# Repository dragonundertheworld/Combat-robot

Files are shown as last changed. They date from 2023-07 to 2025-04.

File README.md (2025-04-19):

# Eternity Fighting Robot Design
Project details can be found in [notion link](https://cherry-room-163.notion.site/0f15df8a2a594116ac27361bd8c10d9d?pvs=4)
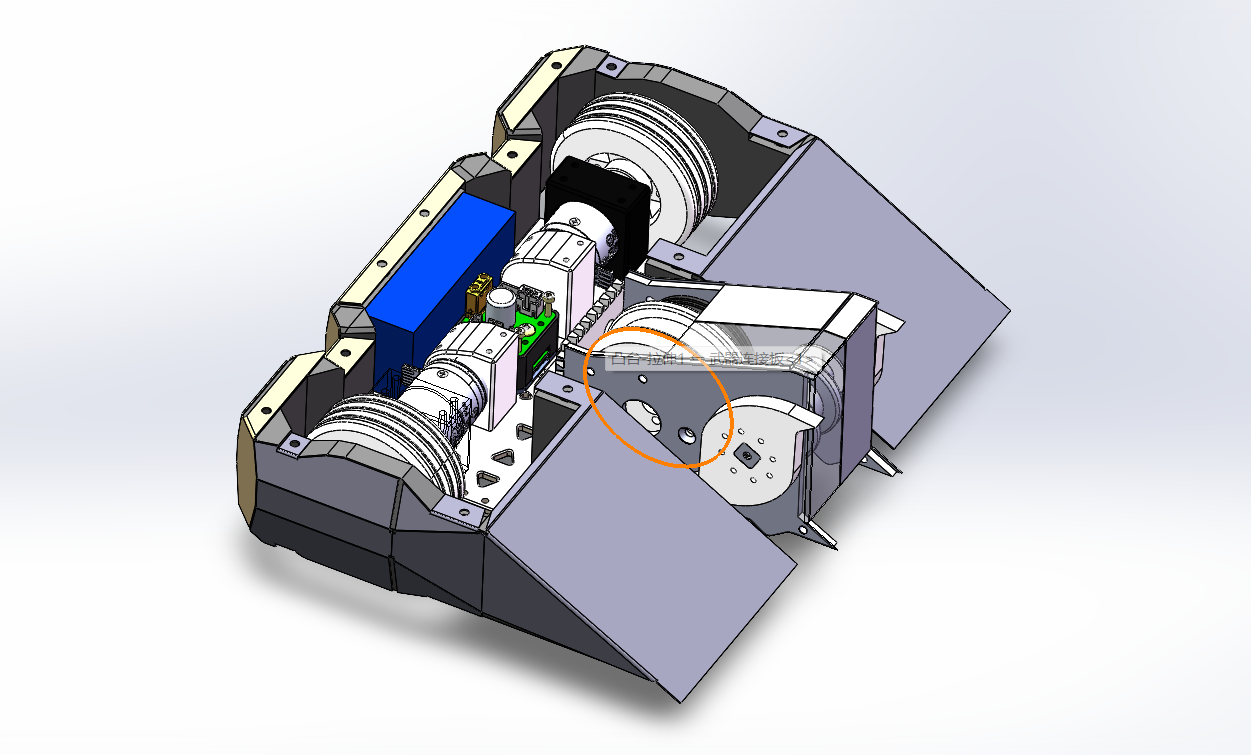
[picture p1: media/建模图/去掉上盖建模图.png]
CAD

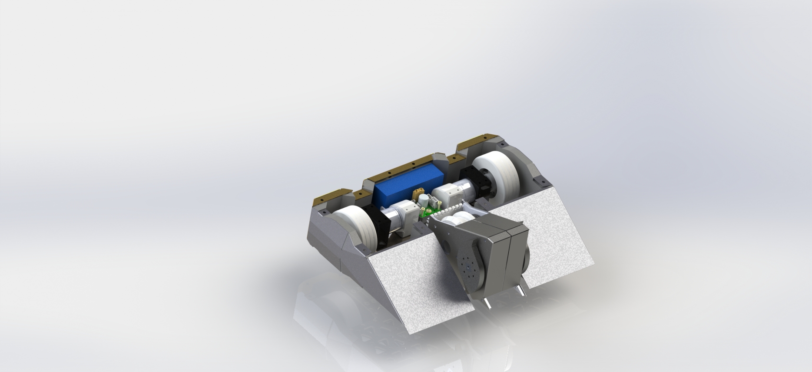
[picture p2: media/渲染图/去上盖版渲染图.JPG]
Rendering

A comprehensive design for a 1v1 “Eternity” fighting robot developed by the University of Electronic Science and Technology of China. This project covers mechanical architecture, drive and attack systems, electronics & control, innovative features, and iterative testing & optimization.

---

## Table of Contents

- [Eternity Fighting Robot Design](#eternity-fighting-robot-design)
  - [Table of Contents](#table-of-contents)
  - [Project Overview](#project-overview)
  - [Mechanical Design](#mechanical-design)
    - [Drive System](#drive-system)
    - [Attack Mechanism](#attack-mechanism)
  - [Electronics \& Control](#electronics--control)
    - [Communication \& Remote Control](#communication--remote-control)
    - [Motor \& Power Components](#motor--power-components)
    - [Main Controller \& Safety](#main-controller--safety)
  - [Innovations \& Materials](#innovations--materials)
    - [Structural Innovations](#structural-innovations)
    - [Material \& Armor](#material--armor)
    - [Modular Architecture](#modular-architecture)
  - [Testing \& Optimization](#testing--optimization)
  - [Team \& Roles](#team--roles)
  - [Build \& Assembly Instructions](#build--assembly-instructions)
  - [License \& Acknowledgements](#license--acknowledgements)

---

## Project Overview

“Eternity” is a compact, four-wheel platform with deployable legs (“4‑wheel 4‑joint” configuration).  
- **Modes**:  
  - **Wheeled mode** for high-speed traversal  
  - **Quasi‑static climbing mode** for stair and obstacle engagement  
- **Climbing cycle**: Approach → Lift → Traction → Reset  
- Maintains stability by keeping at least three “legs” (wheels) in contact with the ground.

---

## Mechanical Design

### Drive System

- **Configuration**: Two‑wheel differential drive  
- **Key Attributes**:
  - Stability
  - Speed control
  - Maneuverability
  - Reliability

### Attack Mechanism

- **Primary Weapon**: Vertical spinner (“tip‑over” rotor)  
- **Supplementary**: Wedge‑style pusher  
- **Advantages**:
  - High-impact vertical blows
  - Low‑profile wedge can lift opponent’s center of gravity  
- **Trade‑offs** vs. horizontal spinners & drum weapons:
  - Reduced “self‑impulse” risk
  - Simpler fabrication and lower cost  
- **Operator Training**: Minimizes precision demands and maximizes damage output.

---

## Electronics & Control

### Communication & Remote Control

- **Technology**: LoRa (Semtech SX1276/78)  
- **Module**: ATK‑LORA  
- **Benefits**:
  1. Long‐range (several kilometers)
  2. Low power consumption
  3. Compact form factor  
- **Interface**: UART

### Motor & Power Components

| Component | Specification |
|---|---|
| **Weapon Motor** | M3508 (no gearbox)  
   - Rated Voltage: 24 V  
   - No‑load Speed: 9,158 rpm  
   - Max Torque: 0.15 Nm |  
| **Weapon ESC**        | C620 Brushless Controller  
   - Weight: 35 g  
   - Voltage: 24 V  
   - Signal: CAN & PWM  
   - Dimensions: 49.4×25.8×11.5 mm |  
| **Drive Motors**      | 2 × Hub motors |  
| **Battery**           | FPV LiPo 3S (11.1 V, 1,300 mAh, 110 C) |

### Main Controller & Safety

- **MCU**: X‑mind C1  
  - Drives up to 5 motor channels via PWM  
  - On‑board screw switch & 3S battery input  
- **CAN Bridge**: F103C8T6  
  - Converts PWM → CAN for ESCs  
- **Safety Systems**:
  1. **Unlock Card**: Limits weapon output to ≤10% if missing  
  2. **Signal Loss Protection**: C8T6 cuts motor commands on remote disconnect  

---

## Innovations & Materials

### Structural Innovations

- **Mortise & Tenon**: “Exposed dovetail” connection for weapon module  
- **Invert Walk**: Weapon top edge co‑planar with wheels when flipped, enabling upside‑down driving

### Material & Armor

- **Weapon Blades**:
  - Manganese steel, 6 mm thick, comma‑shaped tip  
- **Armor**:
  - TPU shell for energy absorption  
- **Tires**:
  - 55 mm high‑friction “camelback” profile

### Modular Architecture

- **Interchangeable Modules**:
  - Rapid swapping of drive, weapon, or armor packs  
  - Simplified maintenance & upgrade paths

---

## Testing & Optimization
[weighting](./media/测试视频/第三版测重.mp4), [drive power testing](./media/测试视频/第三版推力测试.mp4) and [weapon testing](./media/测试视频/第三版武器测试.mp4)
1. **Version 1** – Proof‑of‑concept CAD & basic drive tests  
2. **Version 2** – Refined frame geometry, improved stability  
3. **Version 3** – Acrylic & 3D‑printed prototypes for live arena trials  
4. **Identified Issues**:
   - Excessive overall height  
   - Simplistic armor  
   - Lack of flip resistance  
   - Crowded internal layout  
5. **Optimizations**:
   - Lowered chassis center of gravity  
   - Redesigned armor geometry & thickness  
   - Integrated anti‑flip skids  
   - Re‑routed electronics into wedge cavity for space efficiency

---

## Team & Roles

| Member | Role |
|---|---|
| 曹知寒 | Lead mechanical design; assembly |
| 刘天羽 | Electronics design & control tuning |
| 王启宇 | Mechanical assembly; secondary design; driver |
| 王浩宇 | Team operations & coordination |
| **Advisors** | 何瑜, 彭倍 |

---

## Build & Assembly Instructions

1. **Prerequisites**:  
   - CAD software for 3D model viewing (e.g., SolidWorks, Fusion360)  
   - 3D printer or CNC for prototypes  
2. **Mechanical Assembly**:  
   - Fabricate chassis plates, dovetail fixtures  
   - Install drive & weapon motors with gear mounts  
   - Attach TPU armor panels  
3. **Electrical Wiring**:  
   - Wire X‑mind C1 → F103C8T6 → ESCs (CAN bus)  
   - Route battery & LoRa antenna  
4. **Software Setup**:  
   - Flash microcontroller firmware (STM32CubeIDE)  
   - Configure LoRa remote pairing  
5. **Trial Runs**:  
   - Verify drive control & weapon spin under no‑load  
   - Test safety interlocks (unlock card, signal loss)  
   - Full‑power arena tests with soft obstacles

---

## License & Acknowledgements

- This design is the property of the UESTC.  
- **Disclaimer**: Do not reproduce, distribute, or sell without permission.

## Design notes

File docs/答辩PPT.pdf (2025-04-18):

感谢您下载包图网平台上提供的PPT作品，为了您和包图网以及原创作者的利益，请勿复制、传播、销售，否则将承担法律责任！包图网将对作品进行维权，按照传播下载次数进行十倍的索取赔偿！

# ibaotu.com 电子科技大学

# Eternity

# 格斗机器人设计报告

# 团队成员

# 曹知寒、刘天羽、王启宇、王浩宇

# 指导老师

# 何瑜、彭倍

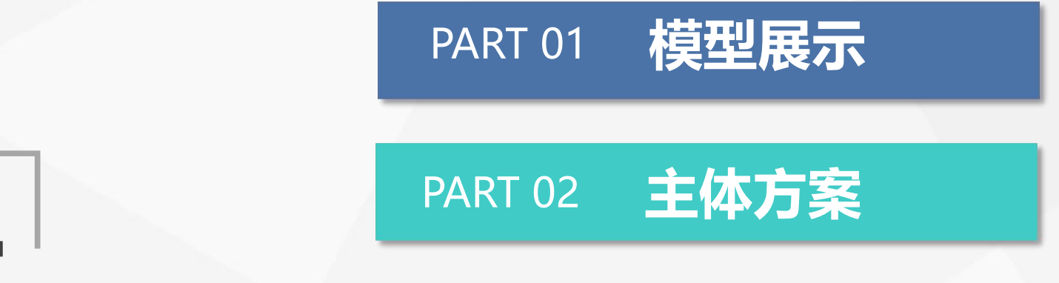
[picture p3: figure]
ibaotu.com; PART 01 模型展示; PART 02; 主体方案

感谢您下载包图网平台上提供的PPT作品，为了您和包图网以及原创作者的利益，请勿复制、传播、销售，否则将承担法律责任！包图网将对作品进行维权，按照传播下载次数进行十倍的索取赔偿！

目录

# CONTENTS

感谢您下载包图网平台上提供的PPT作品，为了您和包图网以及原创作者的利益，请勿复制、传播、销售，否则将承担法律责任！包图网将对作品进行维权，按照传播下载次数进行十倍的索取赔偿！

# ibaotu.com模型展示

01

# ibaotu.com 三维模型渲染图

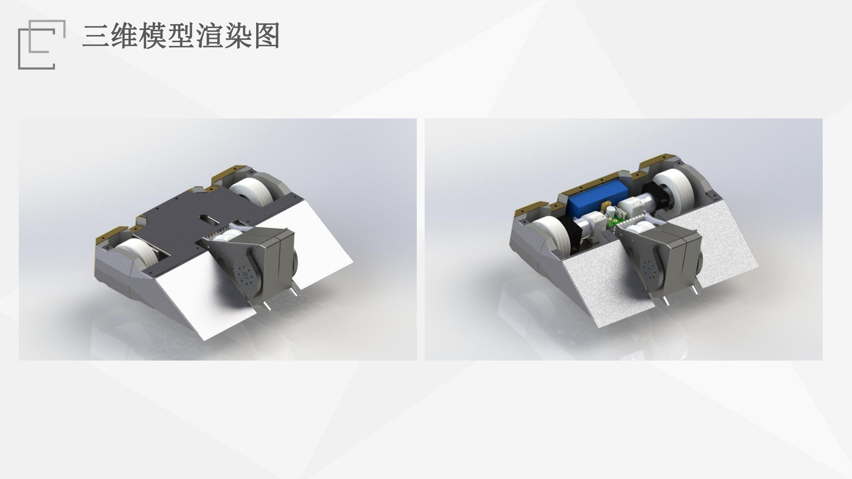
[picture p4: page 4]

感谢您下载包图网平台上提供的PPT作品，为了您和包图网以及原创作者的利益，请勿复制、传播、销售，否则将承担法律责任！包图网将对作品进行维权，按照传播下载次数进行十倍的索取赔偿！

# ibaotu.com 爆炸视图

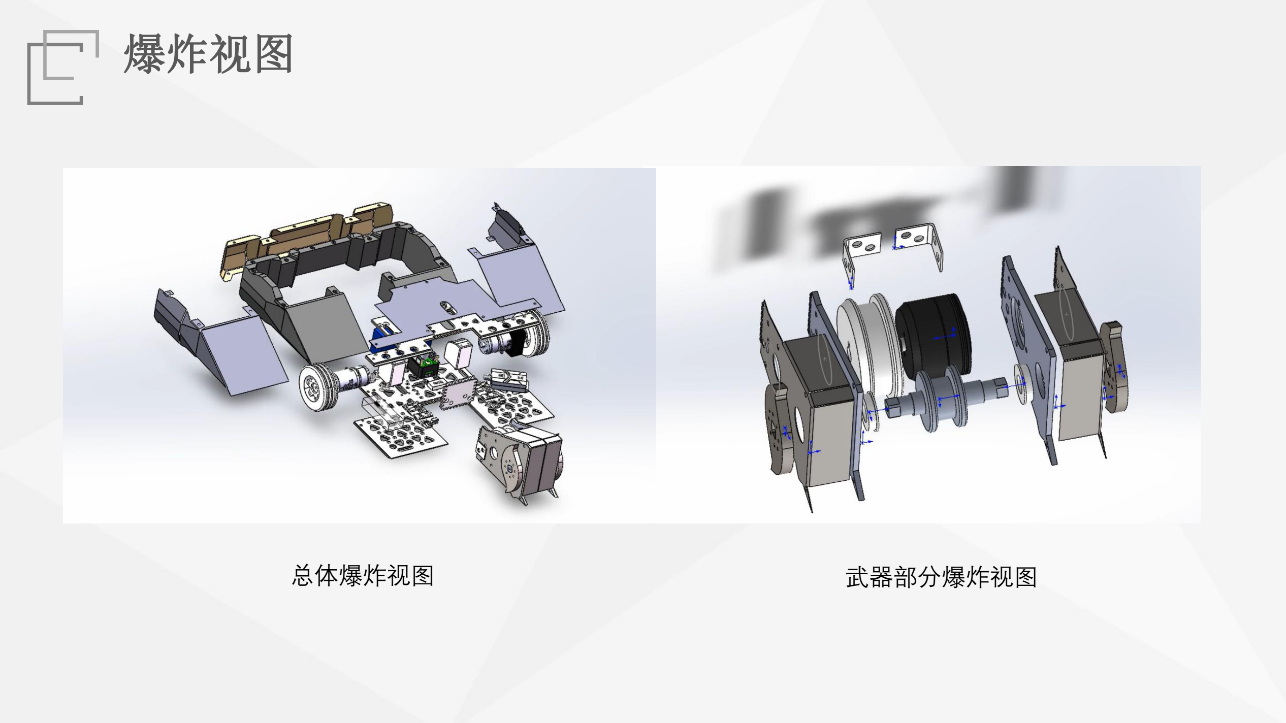
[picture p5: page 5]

感谢您下载包图网平台上提供的PPT作品，为了您和包图网以及原创作者的利益，请勿复制、传播、销售，否则将承担法律责任！包图网将对作品进行维权，按照传播下载次数进行十倍的索取赔偿！

总体爆炸视图 | 武器部分爆炸视图

感谢您下载包图网平台上提供的PPT作品，为了您和包图网以及原创作者的利益，请勿复制、传播、销售，否则将承担法律责任！包图网将对作品进行维权，按照传播下载次数进行十倍的索取赔偿！

# ibaotu.com主体方案

02

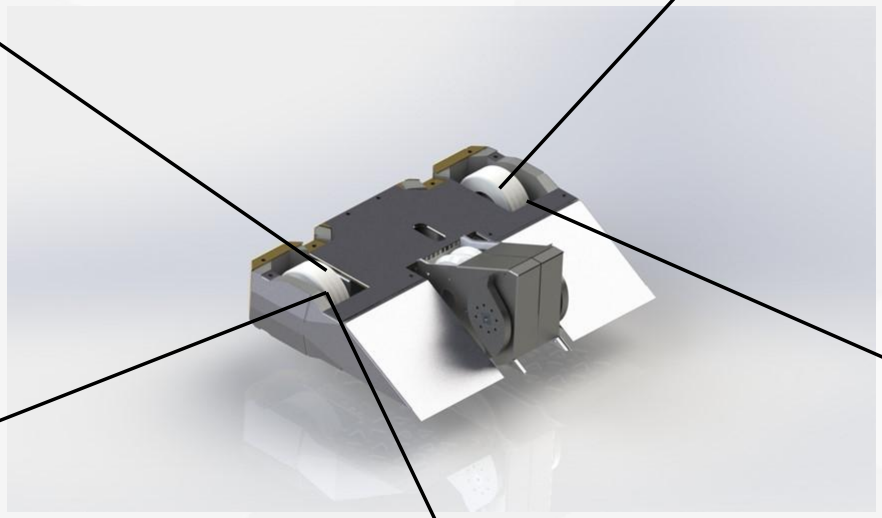
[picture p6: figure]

感谢您下载包图网平台上提供的PPT作品，为了您和包图网以及原创作者的利益，请勿复制、传播、销售，否则将承担法律责任！包图网将对作品进行维权，按照传播下载次数进行十倍的索取赔偿！

# ibaotu.com 移动方式：二轮差速

# 稳定性

控制性 | 快速性

# 灵活性

# 可靠性

感谢您下载包图网平台上提供的PPT作品，为了您和包图网以及原创作者的利益，请勿复制、传播、销售，否则将承担法律责任！包图网将对作品进行维权，按照传播下载次数进行十倍的索取赔偿！

# ibaotu.com 攻击方式：主要使用竖转，辅以楔形攻击

竖转与横转、转鼓和撞击攻击方式的对比 | 缺点
避免被自己的冲击力甩到一边，同时也能 让自己牢牢地抓地 | 对控制者的要求较高

# 增加攻击能量 造成更大的破坏

制造工艺简单且成本低廉 | 相比圆盘或横杆破坏力也较小

# 通过训练控制者，可以最大程度上弥补前两项缺点；同时结合楔形攻击方式的 优点，即可以利用低姿态来铲起对手，可以令对手的重心抬高的同时更好地击 中对方的底部。另外楔形还可以将其他机器人推入竞技场的OUTA区域。

感谢您下载包图网平台上提供的PPT作品，为了您和包图网以及原创作者的利益，请勿复制、传播、销售，否则将承担法律责任！包图网将对作品进行维权，按照传播下载次数进行十倍的索取赔偿！

# ibaotu.com电控方案

03

# ibaotu.com 整体方案

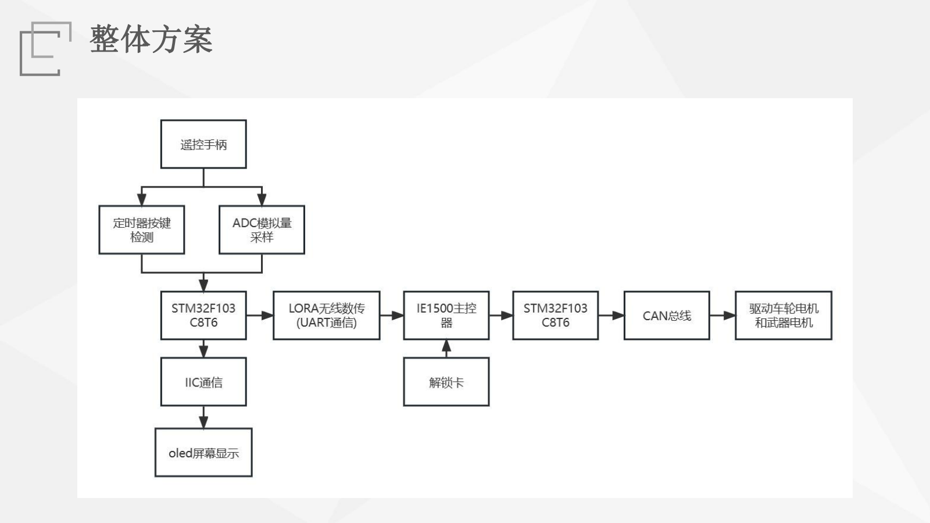
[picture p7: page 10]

感谢您下载包图网平台上提供的PPT作品，为了您和包图网以及原创作者的利益，请勿复制、传播、销售，否则将承担法律责任！包图网将对作品进行维权，按照传播下载次数进行十倍的索取赔偿！

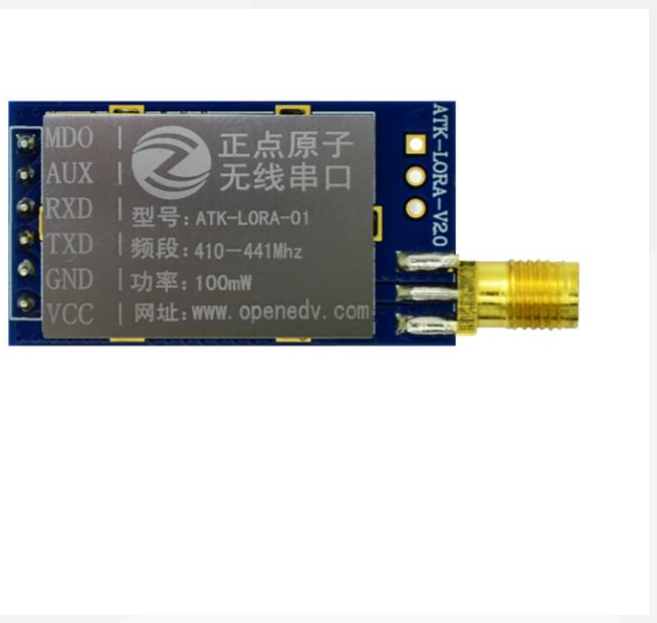
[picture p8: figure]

感谢您下载包图网平台上提供的PPT作品，为了您和包图网以及原创作者的利益，请勿复制、传播、销售，否则将承担法律责任！包图网将对作品进行维权，按照传播下载次数进行十倍的索取赔偿！

# ibaotu.com 遥控系统

# LoRa是一种低功耗远程无线通信技术。它是基于 Semtech公司SX1276/1278芯片开发的无线数传模 块，这种芯片集成规模小、效率高，从而让LoRa 模块拥有高接收灵敏度。

# 1. 作为低功耗广域网的LoRa技术，无线通信距离可以达到几公里，相对WIFI模块而 言，距离要远得多。 2. 相较于无人机常用的遥控接收器，体积更小，且使用UART模式，容易适配多种 遥控器。

# 正点原子ATK-LORA

优势

# ibaotu.com 车轮电机

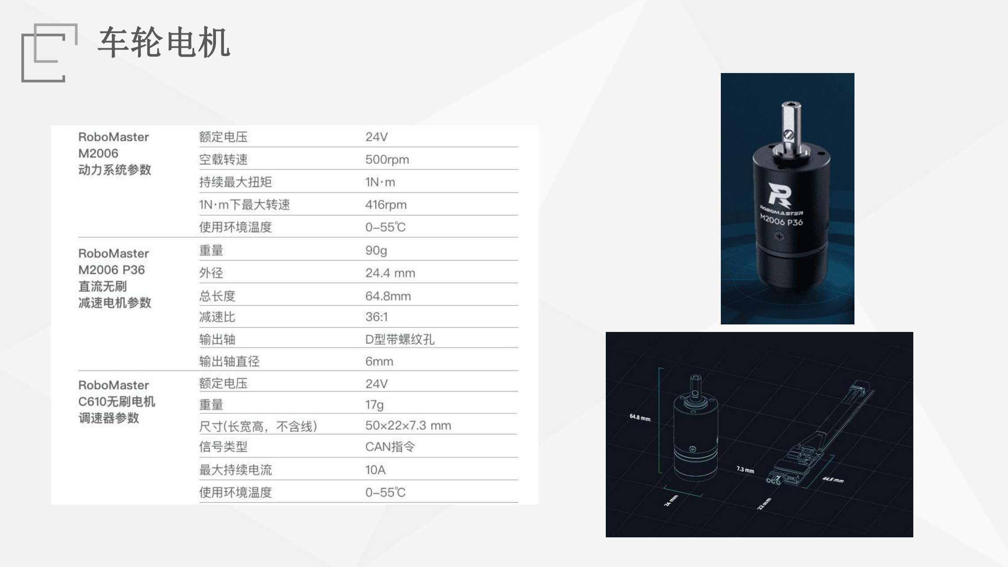
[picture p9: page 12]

感谢您下载包图网平台上提供的PPT作品，为了您和包图网以及原创作者的利益，请勿复制、传播、销售，否则将承担法律责任！包图网将对作品进行维权，按照传播下载次数进行十倍的索取赔偿！

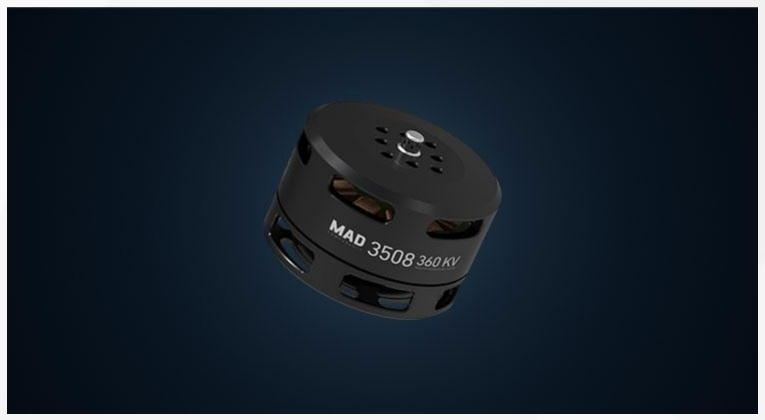
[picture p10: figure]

感谢您下载包图网平台上提供的PPT作品，为了您和包图网以及原创作者的利益，请勿复制、传播、销售，否则将承担法律责任！包图网将对作品进行维权，按照传播下载次数进行十倍的索取赔偿！

# ibaotu.com 武器电机

# 电机型号：M3508(去减速器)

# 额定电压：24V

# 空载转速：9158rpm

# 持续最大扭矩：0.15Nm

# C620无刷电机调速器

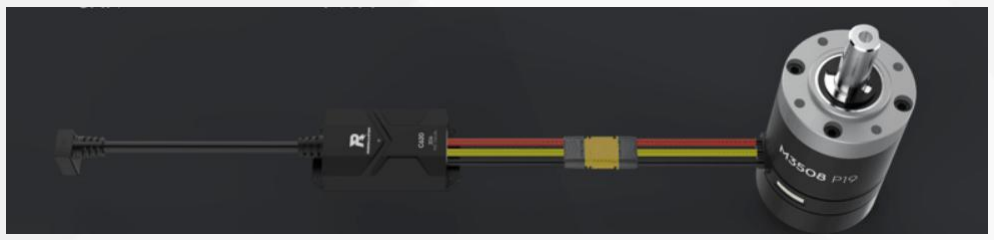
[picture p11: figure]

# 重量:35g 额定电压:24V

# 带线总长度:359mm

# 信号类型:CAN指令、PWM

# 长宽高:49.4*25.8*11.5mm

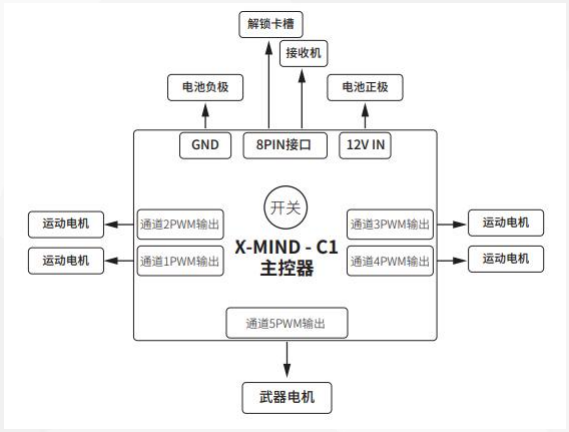
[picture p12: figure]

感谢您下载包图网平台上提供的PPT作品，为了您和包图网以及原创作者的利益，请勿复制、传播、销售，否则将承担法律责任！包图网将对作品进行维权，按照传播下载次数进行十倍的索取赔偿！

# ibaotu.com 主控器

# X-mind C1主控器采用高性能主控芯片，接口 丰富、集成度高，可同 时驱动5套动力系统。

接口：

# 四路运动电机pwm接口

# 一路武器电机pwm接口

# 主控器螺丝开关

# 3S电池供电接口

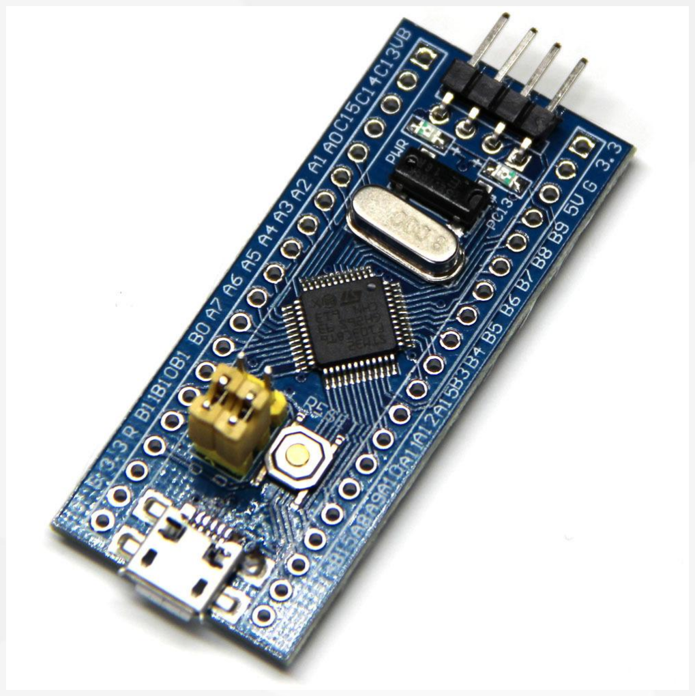
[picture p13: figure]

感谢您下载包图网平台上提供的PPT作品，为了您和包图网以及原创作者的利益，请勿复制、传播、销售，否则将承担法律责任！包图网将对作品进行维权，按照传播下载次数进行十倍的索取赔偿！

# ibaotu.com F103C8T6

# 由于本团队采用的电机控制方式为CAN总线信 号控制，无法直接将主控器的pwm控制信号与 电机直连。

# 因此选用带有CAN信号收发功能的F103C8T6作 为信号转发，在接受主控器pwm信号的同时向 电机发送CAN总线信号。

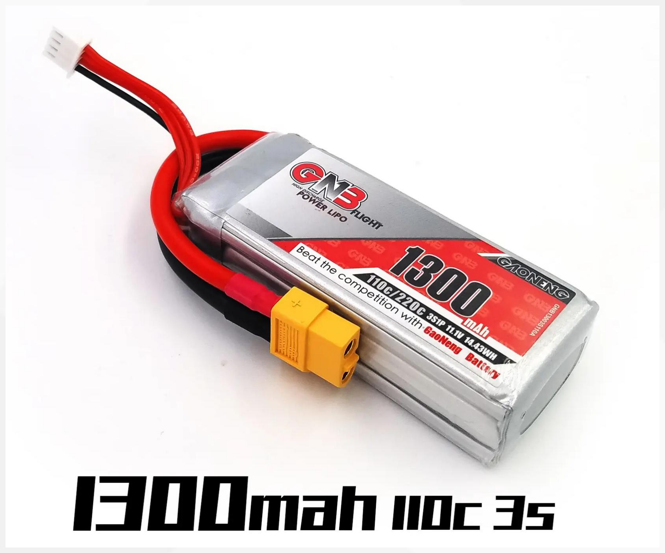
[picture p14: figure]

感谢您下载包图网平台上提供的PPT作品，为了您和包图网以及原创作者的利益，请勿复制、传播、销售，否则将承担法律责任！包图网将对作品进行维权，按照传播下载次数进行十倍的索取赔偿！

# ibaotu.com 电池

# FPV穿越机电池

# 3s/电压11.1V

# 1300mah 110c

感谢您下载包图网平台上提供的PPT作品，为了您和包图网以及原创作者的利益，请勿复制、传播、销售，否则将承担法律责任！包图网将对作品进行维权，按照传播下载次数进行十倍的索取赔偿！

ibaotu.com 电控 | 机器人安全系统

# 解锁卡功能 当X-mind C1主控器未插入解锁卡时，武器电机控制通道的输出功率将低于最 大输出功率的10%。

# 遥控安全功能 当无遥控信号异常时，C8T6会主动停止发送电机端的控制信号，防止小车失控。

感谢您下载包图网平台上提供的PPT作品，为了您和包图网以及原创作者的利益，请勿复制、传播、销售，否则将承担法律责任！包图网将对作品进行维权，按照传播下载次数进行十倍的索取赔偿！

# ibaotu.com自主创新

04

# ibaotu.com 结构创新

# 武器模块与车身的连接采用榫卯结构中的明燕尾榫，

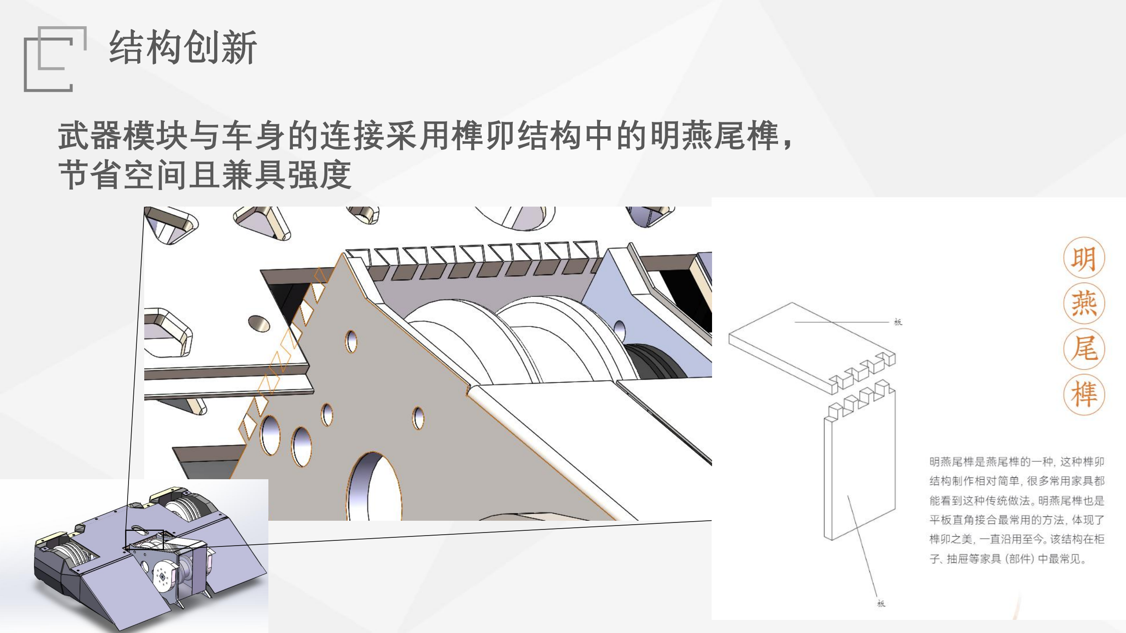
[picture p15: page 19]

感谢您下载包图网平台上提供的PPT作品，为了您和包图网以及原创作者的利益，请勿复制、传播、销售，否则将承担法律责任！包图网将对作品进行维权，按照传播下载次数进行十倍的索取赔偿！

# 节省空间且兼具强度

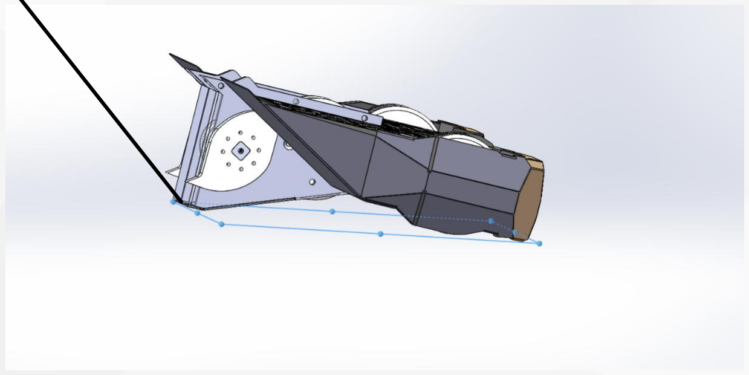
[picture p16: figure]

感谢您下载包图网平台上提供的PPT作品，为了您和包图网以及原创作者的利益，请勿复制、传播、销售，否则将承担法律责任！包图网将对作品进行维权，按照传播下载次数进行十倍的索取赔偿！

# ibaotu.com 结构创新

# 武器壁板的最高点倒立行走 时与轮胎处于同一平面，在 倒立时仍然能够正常运行。

# 倒立行进支点

# 倒立行走结构

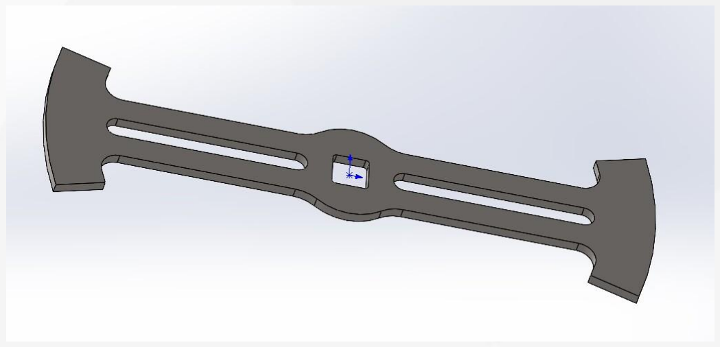
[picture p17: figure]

感谢您下载包图网平台上提供的PPT作品，为了您和包图网以及原创作者的利益，请勿复制、传播、销售，否则将承担法律责任！包图网将对作品进行维权，按照传播下载次数进行十倍的索取赔偿！

# ibaotu.com 结构创新

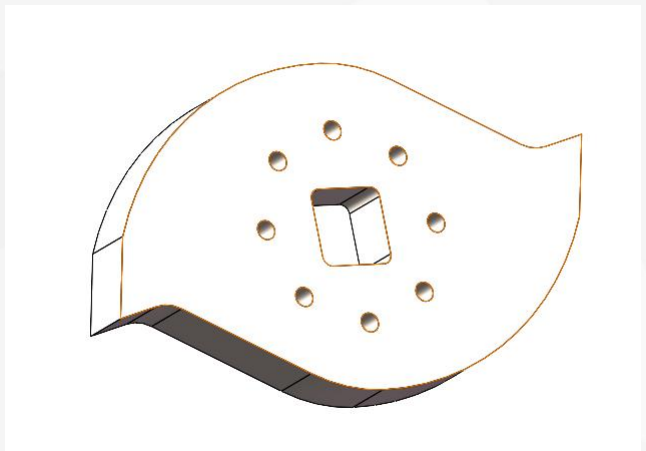
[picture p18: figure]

# 1. 采用锰钢材料，能够承受较大的冲击 力和摩擦力而不容易变形或损坏。 2. 刀片厚度为6mm，保证强度和冲击力。 3. 刀片形状设计为逗号型，能保证尖端 命中对方车辆从而造成最大伤害。

# 刀片设计

# 之前存在的问题：

# 刀片攻击效果不够理想，且不适应竖转的攻击模式。

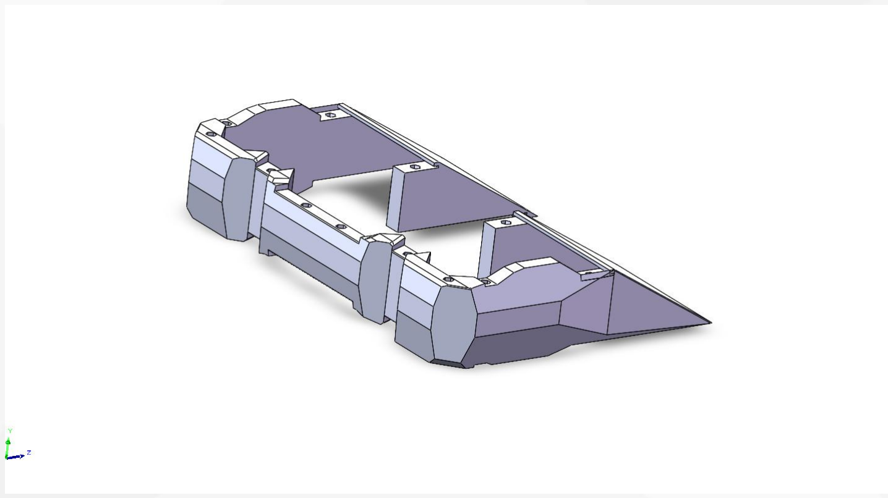
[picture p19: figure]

感谢您下载包图网平台上提供的PPT作品，为了您和包图网以及原创作者的利益，请勿复制、传播、销售，否则将承担法律责任！包图网将对作品进行维权，按照传播下载次数进行十倍的索取赔偿！

# ibaotu.com 材料创新

# 护甲采用tpu材料

# 1. 方便做成一体化 2. 方便做成任意形状 3. 可有效吸能。

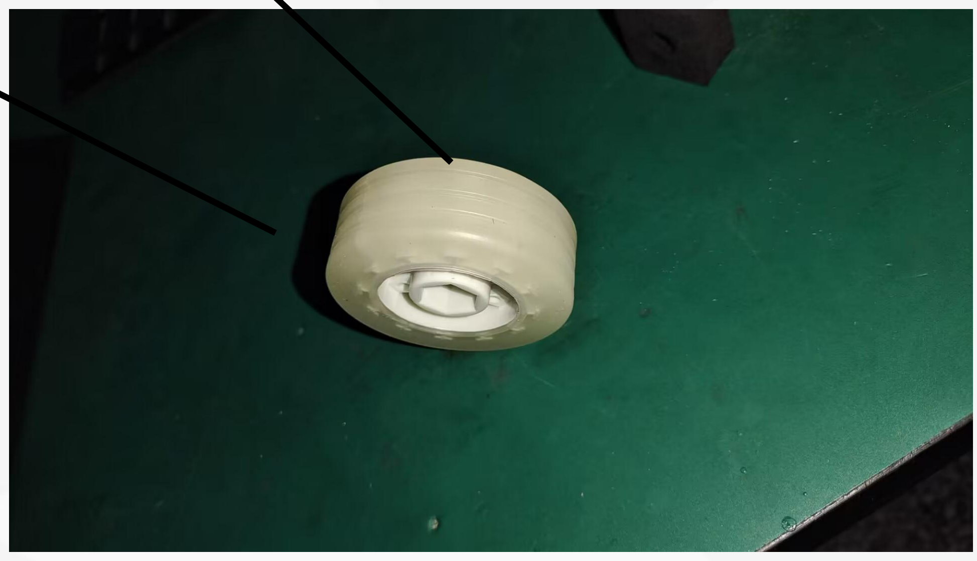
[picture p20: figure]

感谢您下载包图网平台上提供的PPT作品，为了您和包图网以及原创作者的利益，请勿复制、传播、销售，否则将承担法律责任！包图网将对作品进行维权，按照传播下载次数进行十倍的索取赔偿！

# ibaotu.com 材料创新

# 耐磨性好

# 1. 耐磨性好 2. 抗压性强 3. 抓地力强 4. 重量轻 5. 直径小，车辆底盘更低，稳定性更强

# 抗压性强

# 轮胎选择：55mm高摩擦力驼峰轮胎

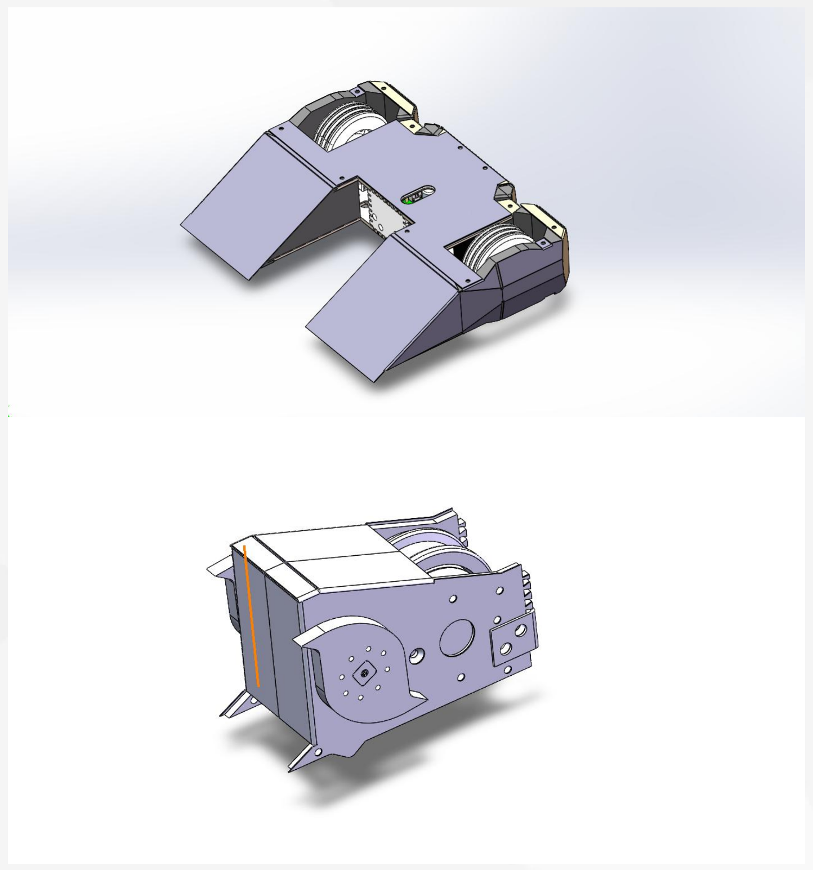
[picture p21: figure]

感谢您下载包图网平台上提供的PPT作品，为了您和包图网以及原创作者的利益，请勿复制、传播、销售，否则将承担法律责任！包图网将对作品进行维权，按照传播下载次数进行十倍的索取赔偿！

# ibaotu.com 设计创新

# 机器人主体与武器模块采用模块化设计

# 1.维护性: 如果机器人的某个部件损坏，只需要更换相应 的模块即可，这样维修成本较低并且更快速，不会影响整 个机器人的工作效率。 2.改进可行性: 采用模块化的结构，提高了机器人的升级、 改进的可行性。

感谢您下载包图网平台上提供的PPT作品，为了您和包图网以及原创作者的利益，请勿复制、传播、销售，否则将承担法律责任！包图网将对作品进行维权，按照传播下载次数进行十倍的索取赔偿！

# ibaotu.com 测试与优化

05

# ibaotu.com 第一版

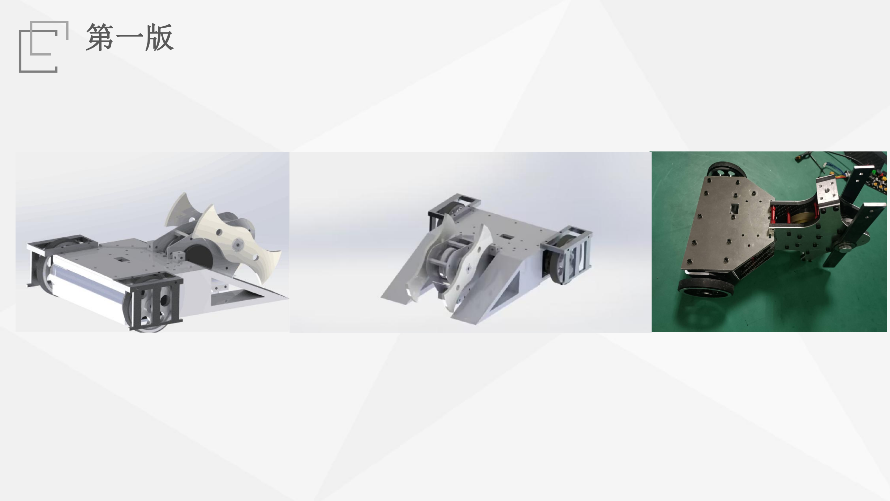
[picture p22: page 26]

感谢您下载包图网平台上提供的PPT作品，为了您和包图网以及原创作者的利益，请勿复制、传播、销售，否则将承担法律责任！包图网将对作品进行维权，按照传播下载次数进行十倍的索取赔偿！

# ibaotu.com 第二版

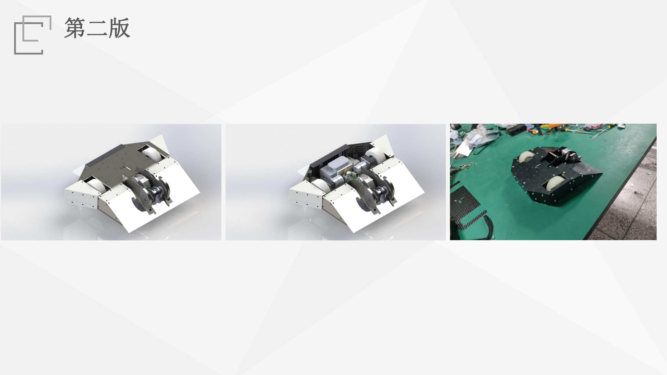
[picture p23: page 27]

感谢您下载包图网平台上提供的PPT作品，为了您和包图网以及原创作者的利益，请勿复制、传播、销售，否则将承担法律责任！包图网将对作品进行维权，按照传播下载次数进行十倍的索取赔偿！

# ibaotu.com 第三版

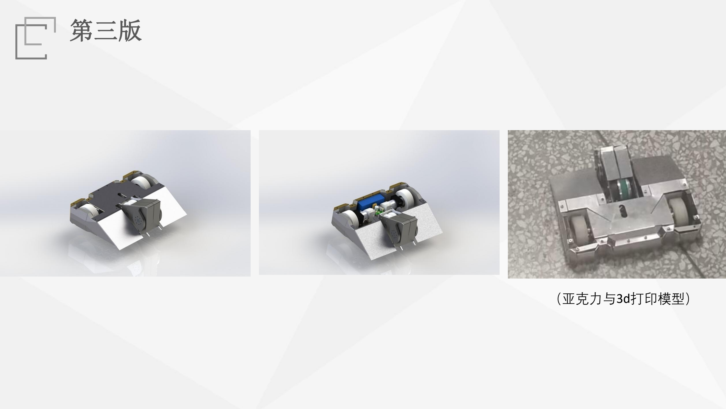
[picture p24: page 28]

感谢您下载包图网平台上提供的PPT作品，为了您和包图网以及原创作者的利益，请勿复制、传播、销售，否则将承担法律责任！包图网将对作品进行维权，按照传播下载次数进行十倍的索取赔偿！

# （亚克力与3d打印模型）

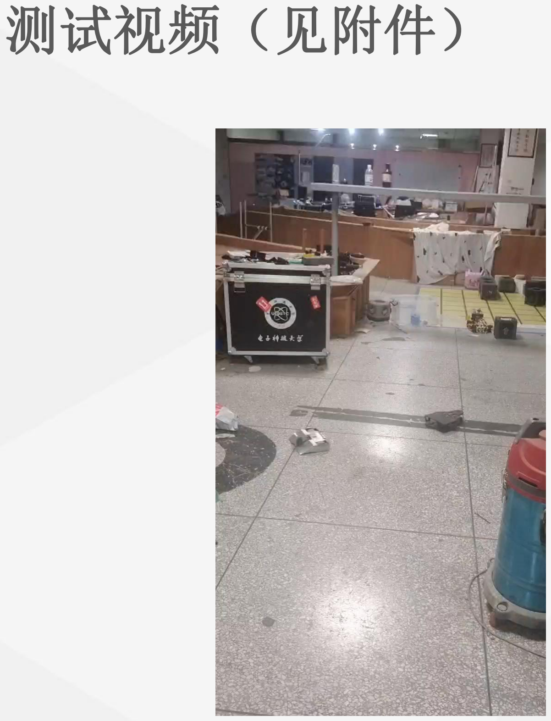
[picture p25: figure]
ibaotu.com 测试视频（见附件）
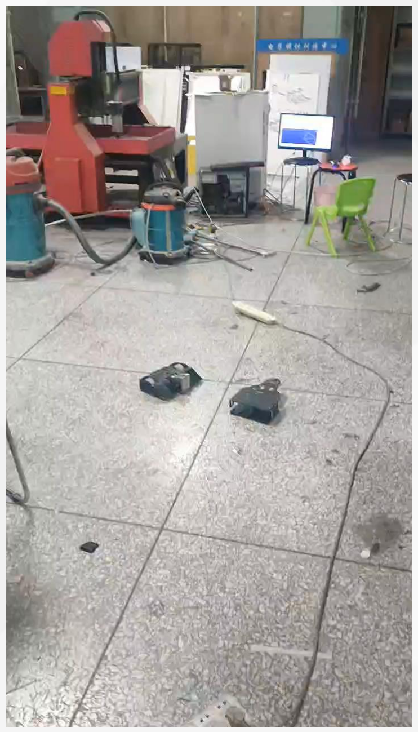
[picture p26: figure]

感谢您下载包图网平台上提供的PPT作品，为了您和包图网以及原创作者的利益，请勿复制、传播、销售，否则将承担法律责任！包图网将对作品进行维权，按照传播下载次数进行十倍的索取赔偿！

感谢您下载包图网平台上提供的PPT作品，为了您和包图网以及原创作者的利益，请勿复制、传播、销售，否则将承担法律责任！包图网将对作品进行维权，按照传播下载次数进行十倍的索取赔偿！

# ibaotu.com 之前存在的问题：

# 1. 作为采用竖转攻击方式的机器人，车身包括武器部分高度过高，影响比赛中的 格斗效果； 2. 护甲设计较为简陋，不能很好的保护机器人； 3. 没有防翻设计，容易出现后翻以及侧翻的情况； 4. 车轮布局，车体内部各元件布局欠妥，各电路元件较拥挤。

# 针对这些问题我们作出了以下优化：

# 1. 优化各部件结构以及连接方式； 2. 重新设计车体布局，车体偏向于更低； 3. 重新设计护甲，使其在具有足够结构刚度的情况下达到最小重量与最理想的外

观；

# 4. 利用楔形部分空间布置电路元件，使布局更合理

# 车体部分

感谢您下载包图网平台上提供的PPT作品，为了您和包图网以及原创作者的利益，请勿复制、传播、销售，否则将承担法律责任！包图网将对作品进行维权，按照传播下载次数进行十倍的索取赔偿！

# ibaotu.com 成员分工

# 成员分工 曹知寒：主机械设计，辅机械组装 刘天羽：电路设计及控制调试 王启宇：主机械组装，辅机械设计，操作手 王浩宇：团队运营，辅助协调沟通

感谢您下载包图网平台上提供的PPT作品，为了您和包图网以及原创作者的利益，请勿复制、传播、销售，否则将承担法律责任！包图网将对作品进行维权，按照传播下载次数进行十倍的索取赔偿！

# ibaotu.com 谢谢

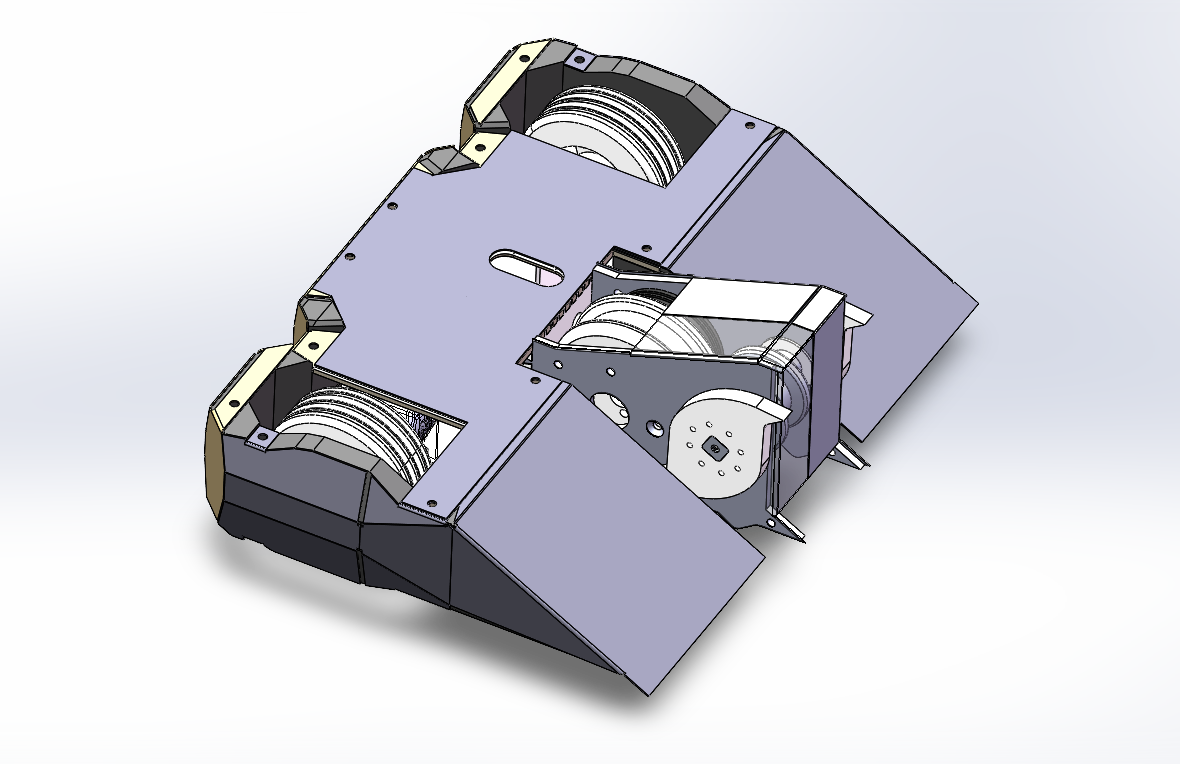
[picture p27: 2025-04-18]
media/建模图/整体建模图.png

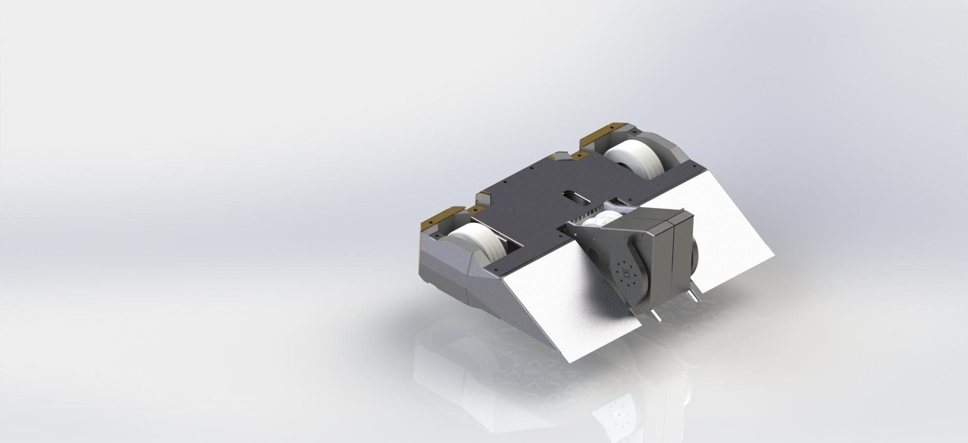
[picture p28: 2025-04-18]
media/渲染图/整车渲染图.JPG

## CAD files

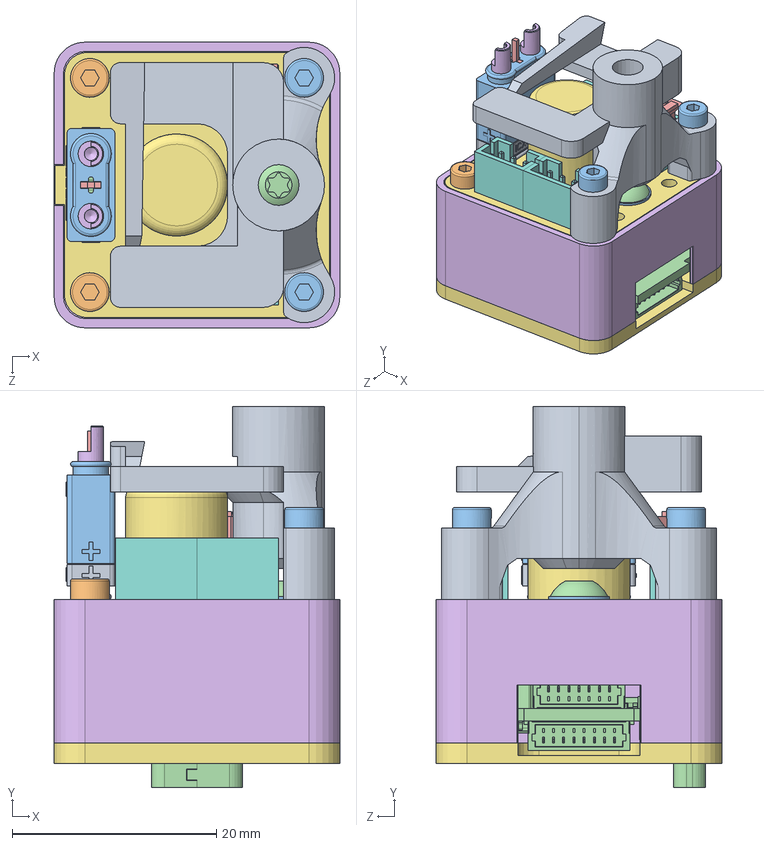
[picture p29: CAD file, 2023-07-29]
assets/行驶模块0716/标件/m2006电机和主控器模块(无线版)/安全主控器模块.stp.SLDASM
28.0 x 37.3 x 28.0 mm
ICS3010002.stp
ICS30100.stp x 2
ICS3010004.stp
ICS3010006.stp
ICS3010007.stp
ICS30100_1.stp x 2
PCB000.stp
PH2-3.stp x 4
PCB0002.stp
SH1-7.stp
001_2.stp
002.stp
M2000.stp x 4
0021.stp
0022.stp
GB2673-M2X10-8_8.stp x 4
0023.stp
GB70_1-M2X6-8_8.stp x 2
GB70_1-M2X12-8_8.stp x 2
GB70_2-M3X6-12_9.stp
PH2-0.stp

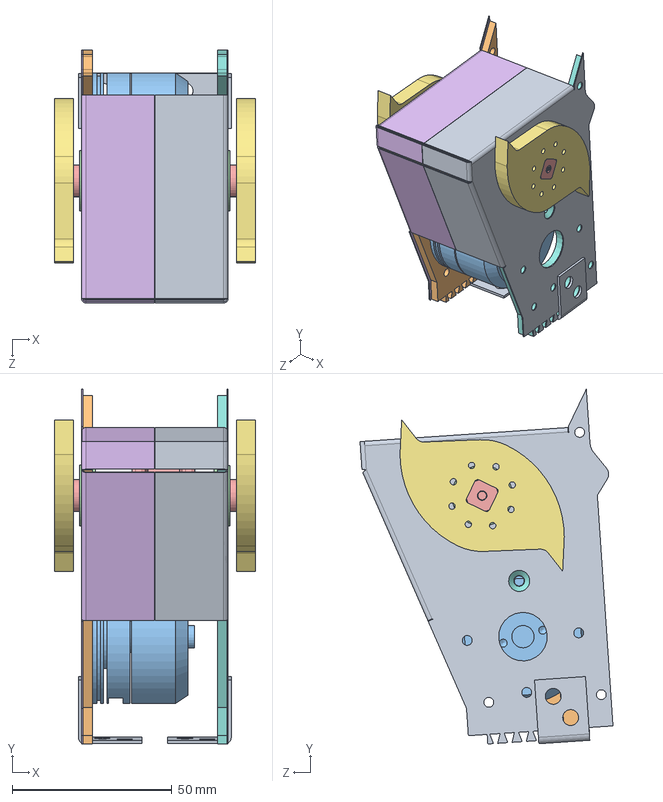
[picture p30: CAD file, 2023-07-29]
assets/武器模块0717/武器模块.SLDASM
63.0 x 111.2 x 79.2 mm
武器右臂板
3508电机
10-19-5法兰轴承 x 2
转轴
武器右臂板-钣金
竖转刀片.SLDPRT x 2
武器左臂板0712
武器左臂板-钣金
L型支架 x 2

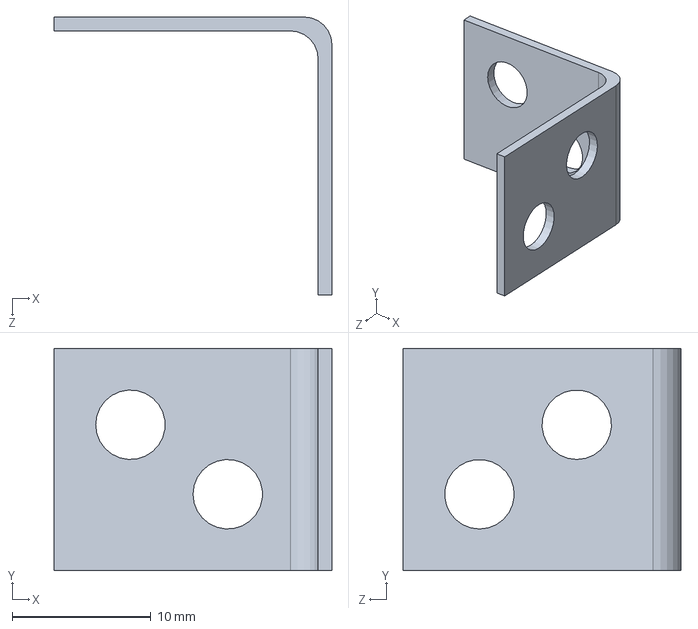
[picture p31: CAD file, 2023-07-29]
assets/武器模块0717/L型支架.SLDPRT
20.0 x 16.0 x 20.0 mm

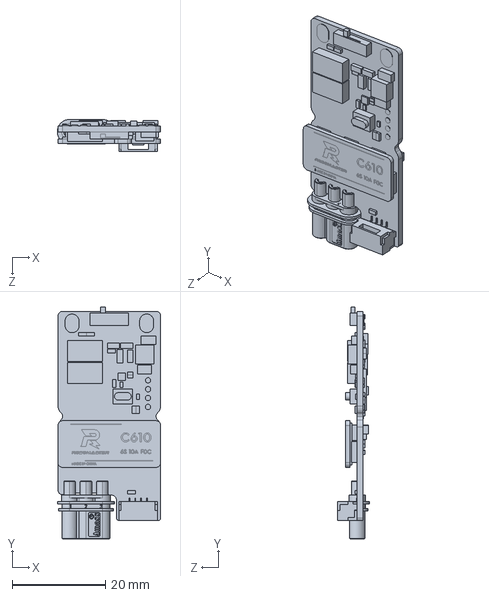
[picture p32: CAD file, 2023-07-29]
assets/行驶模块0716/标件/m2006电机和主控器模块(无线版)/C610电调.step.SLDPRT
22.1 x 49.7 x 6.90 mm

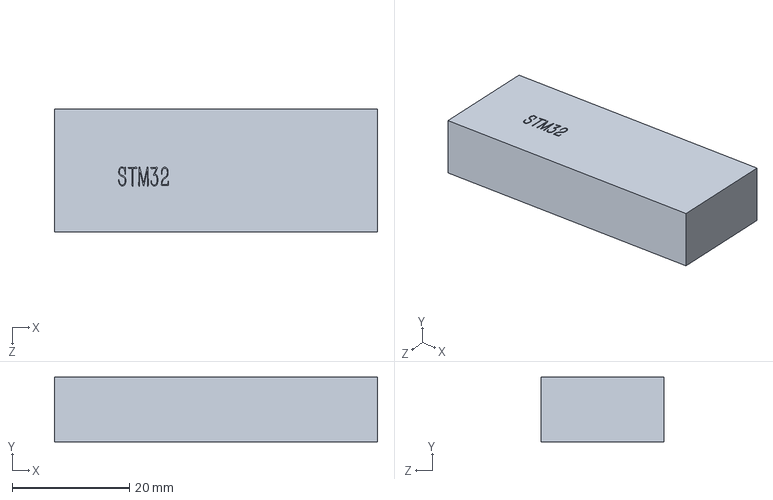
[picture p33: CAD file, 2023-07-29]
assets/行驶模块0716/标件/stm32.SLDPRT
55.0 x 11.0 x 21.0 mm

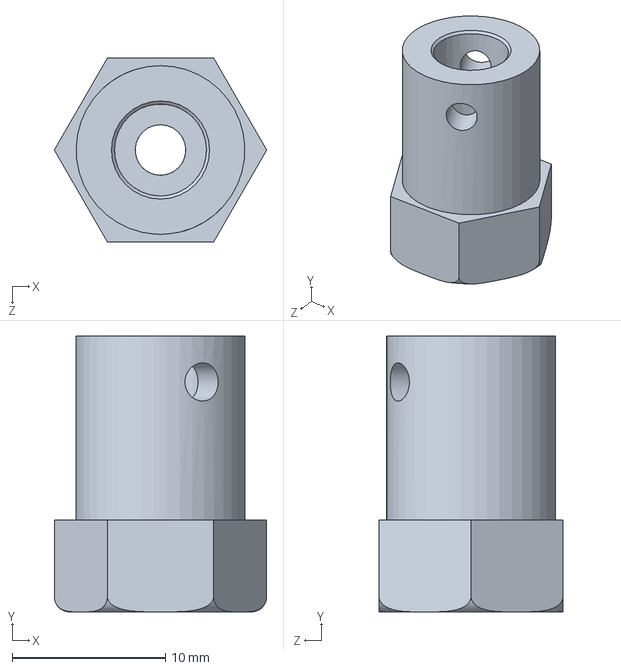
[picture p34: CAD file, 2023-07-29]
assets/行驶模块0716/轮-轴-机-支撑/联轴器.SLDPRT.sldprt
13.9 x 18.0 x 12.0 mm

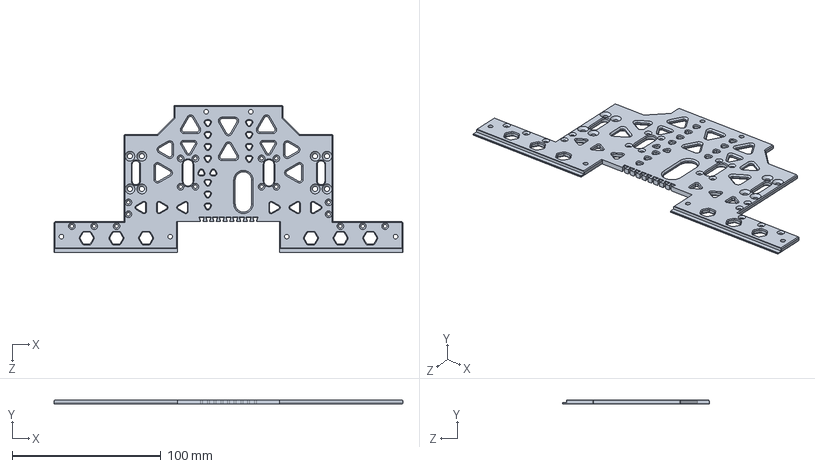
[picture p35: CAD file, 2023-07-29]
assets/行驶模块0716/非标件/行驶上板2.0.SLDPRT
234.4 x 3.00 x 99.1 mm

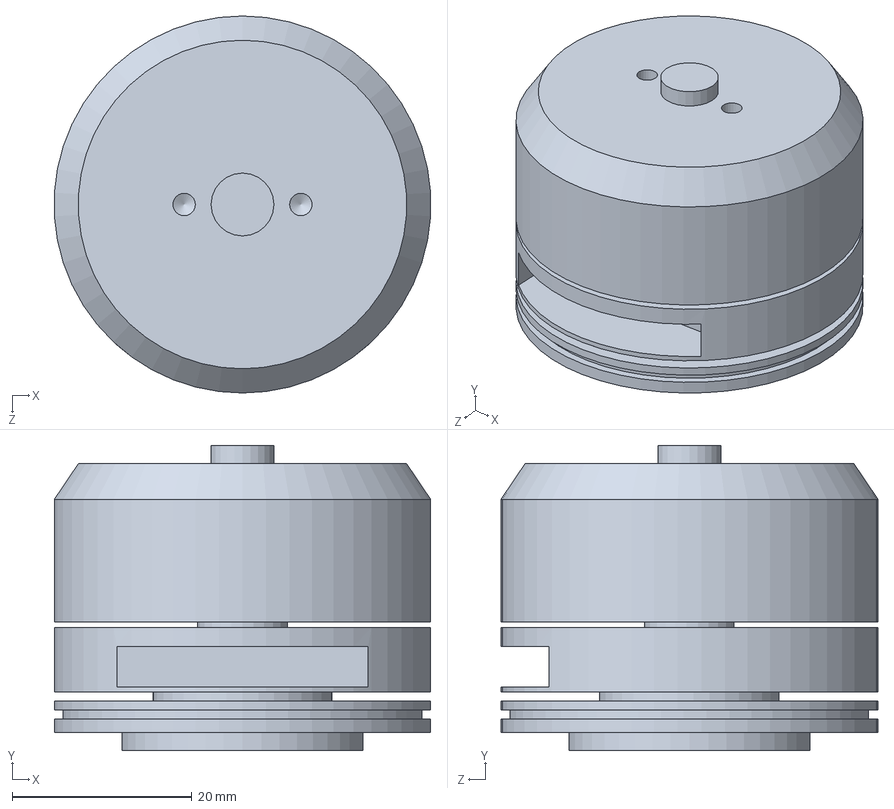
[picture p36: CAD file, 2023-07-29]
assets/武器模块0717/3508电机.SLDPRT
41.9 x 34.0 x 42.0 mm

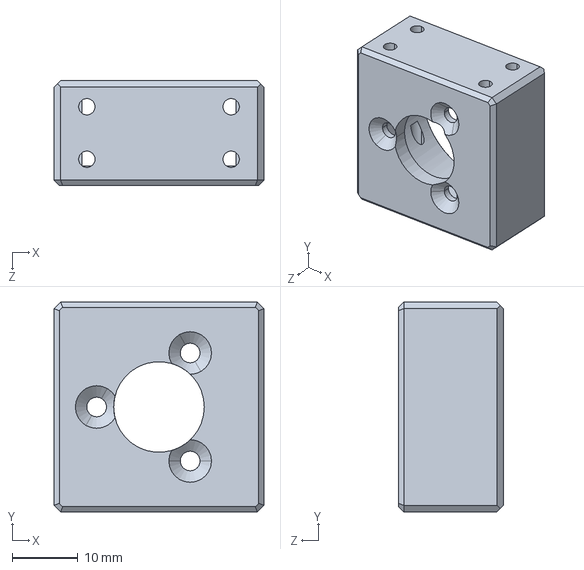
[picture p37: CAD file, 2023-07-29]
assets/行驶模块0716/标件/m2006电机和主控器模块(无线版)/天之博特M2006电机支架普通版.step.SLDPRT
32.0 x 32.0 x 16.0 mm

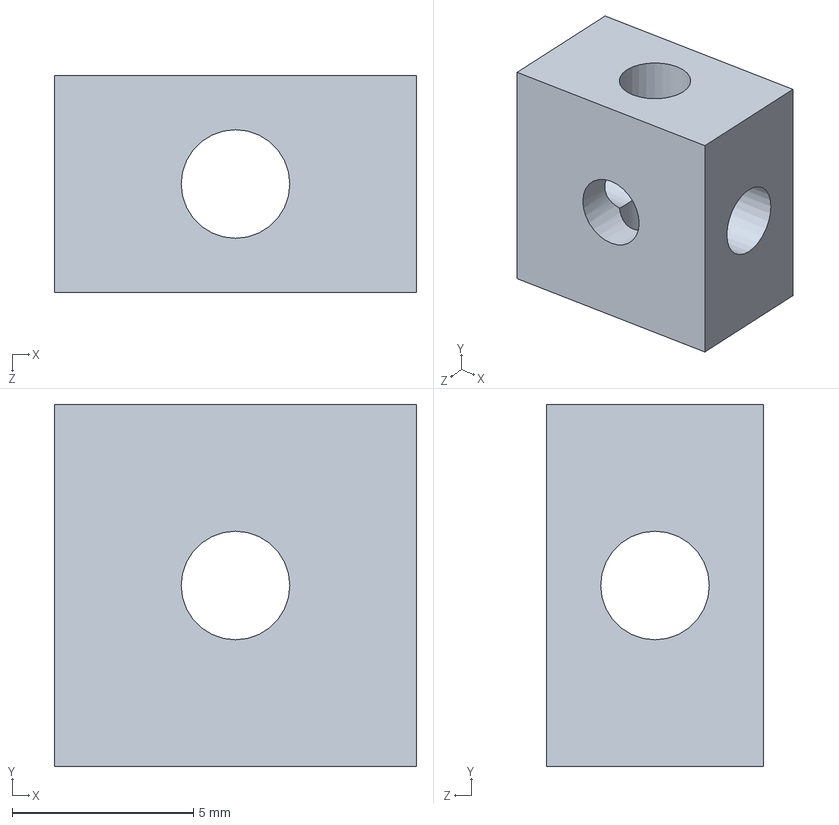
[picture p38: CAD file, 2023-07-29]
assets/行驶模块0716/标件/角码.SLDPRT
10.0 x 10.0 x 6.00 mm

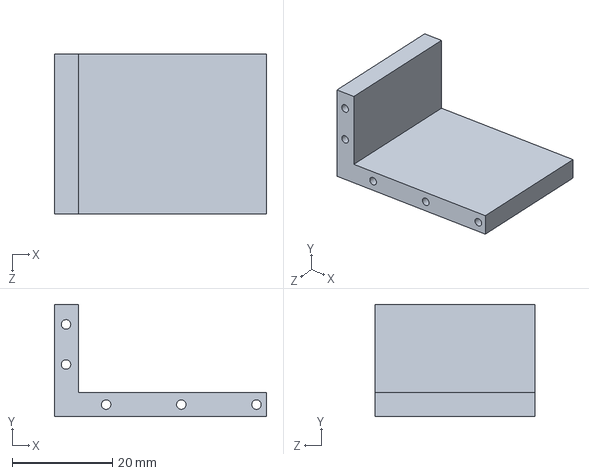
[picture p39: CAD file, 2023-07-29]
assets/行驶模块0716/非标件/轮子隔离板.SLDPRT
42.3 x 22.4 x 32.0 mm

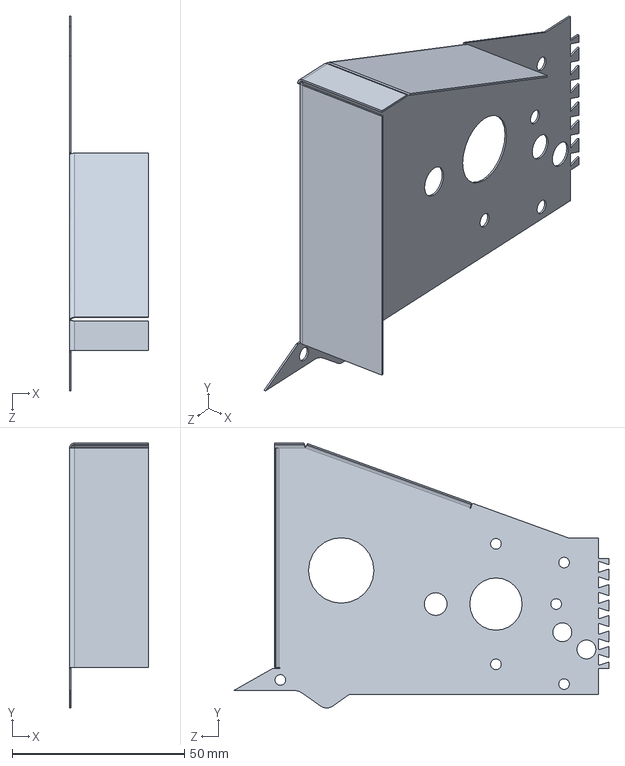
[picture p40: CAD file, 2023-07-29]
assets/武器模块0717/武器左臂板-钣金.SLDPRT
22.9 x 77.0 x 108.8 mm

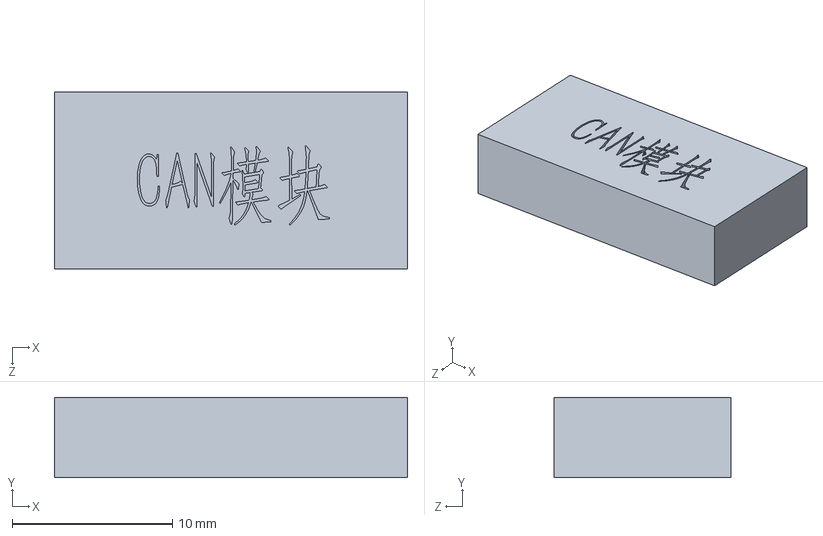
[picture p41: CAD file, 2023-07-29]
assets/行驶模块0716/标件/CAN模块.SLDPRT
22.0 x 5.00 x 11.0 mm

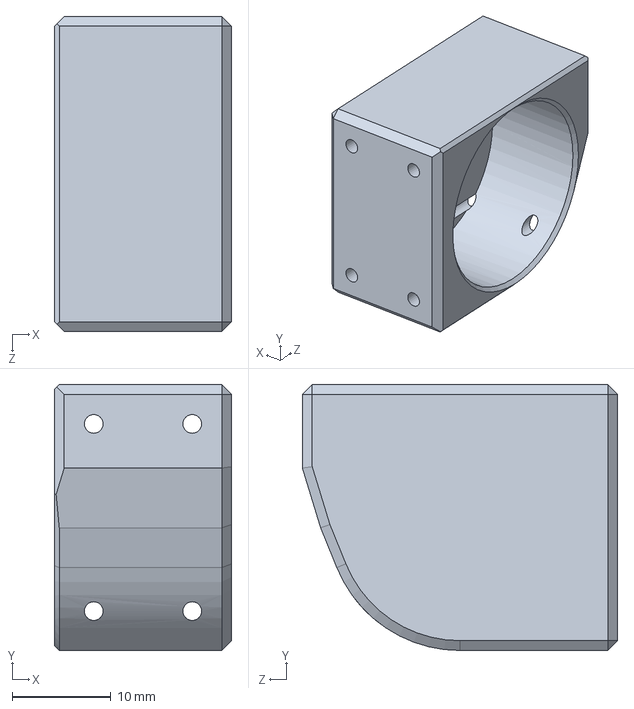
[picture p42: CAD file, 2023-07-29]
assets/行驶模块0716/非标件/行驶电机轴支架.SLDPRT
18.0 x 27.0 x 32.0 mm

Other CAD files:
assets/武器模块0717/武器左臂板0712.SLDPRT
assets/行驶模块0716/标件/电池.SLDPRT
assets/行驶模块0716/非标件/行驶上板钣金.SLDPRT
assets/武器模块0717/10-19-5法兰轴承.SLDPRT
assets/武器模块0717/同步带护甲.SLDPRT
assets/武器模块0717/新皮带轮.SLDPRT
assets/武器模块0717/武器-行驶连接板.SLDPRT
assets/武器模块0717/武器右臂板-钣金.SLDPRT
assets/武器模块0717/武器右臂板.SLDPRT
assets/武器模块0717/竖转刀片.SLDPRT.sldprt
assets/武器模块0717/转轴.SLDPRT
assets/行驶模块0716/非标件/tpu护甲.SLDPRT
assets/行驶模块0716/非标件/tpu护甲后钣金.SLDPRT
assets/行驶模块0716/非标件/tpu护甲左右钣金.SLDPRT
assets/行驶模块0716/非标件/主控器固定座.SLDPRT
assets/行驶模块0716/非标件/武器连接板.SLDPRT
assets/行驶模块0716/非标件/行驶底板2.0.SLDPRT
assets/行驶模块0716/非标件/镜向tpu护甲左右钣金.SLDPRT
